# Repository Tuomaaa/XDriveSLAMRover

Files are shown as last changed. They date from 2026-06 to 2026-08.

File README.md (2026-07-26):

# SummerSLAM

SummerSLAM is a 12-week, hardware-backed study of mobile-robot localization
and SLAM on a four-wheel X-drive rover. The public engineering notes share the
design process, failures, measurements, and reproduction path for the first six
weeks, from hardware bring-up through Monte Carlo Localization.

**Reproduction manual / engineering notes:** <https://tuomaaa.github.io/XDriveSLAMRover/>

## Repository map

- `stm32/` - STM32F411 firmware, motor control, encoders, CAN, and ultrasonic sensing
- `ros2_ws/src/` - ROS 2 Jazzy CAN bridge, odometry, measurement models, and localization tools
- `data/` - calibration and validation data
- `docs/textbook/` - Sphinx/MyST source for the Week 1-6 engineering notes
- `PROJECT_STATE.md` - current status, decisions, known issues, and next steps

## Licensing

Original software in this repository is licensed under the [MIT License](LICENSE).
Original engineering-note content and media are licensed under
[CC BY 4.0](LICENSE-DOCS). Third-party components retain their own licenses.

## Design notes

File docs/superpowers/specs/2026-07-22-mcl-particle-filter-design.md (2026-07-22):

# Week 6: MCL Particle Filter — Design Spec

## Goal

Implement Monte Carlo Localization (Prob Robotics Ch.8) for the X-drive rover
in a known rectangular environment, using encoder odometry for prediction and
two HC-SR04 ultrasonic sensors for measurement update.

## Modules

| File | Responsibility | Dependencies |
|---|---|---|
| `mcl.py` | Particle filter core (predict, update, estimate, resample) | `map_model.py`, `measurement_model.py`, numpy |
| `mcl_offline.py` | Offline replay: read CSV, run MCL, produce animation GIF | `mcl.py`, matplotlib |
| `mcl_node.py` | Online ROS2 node (phase 2, after offline validation) | `mcl.py`, rclpy |

All files live in `ros2_ws/src/` alongside existing modules.

## `mcl.py` — Core Algorithm

### Class: `MCL`

```python
MCL(
    rect_map: RectMap,
    beam_model: BeamModel,
    sensor_configs: list[tuple[float, tuple[float, float]]],
    num_particles: int = 500,
    alpha: tuple[float, float, float, float] = (0.05, 0.01, 0.01, 0.05),
    rng_seed: int | None = None,
)
```

**State:**
- `particles`: numpy array shape (N, 3) — each row is (x, y, theta)
- `weights`: numpy array shape (N,) — normalized to sum to 1

**Methods:**

`initialize(x, y, theta, xy_spread, theta_spread)` — scatter particles as
Gaussian cloud around a known starting pose. All particles get weight 1/N.

`predict(dx_body, dy_body, dtheta)` — for each particle:
1. Add proportional Gaussian noise to the body-frame delta:
   - `d_trans = sqrt(dx^2 + dy^2)`
   - `dx' = dx + N(0, alpha[0]*d_trans + alpha[1]*|dtheta|)`
   - `dy' = dy + N(0, alpha[0]*d_trans + alpha[1]*|dtheta|)`
   - `dtheta' = dtheta + N(0, alpha[2]*d_trans + alpha[3]*|dtheta|)`
2. Rotate (dx', dy') from body frame to world frame using particle's theta
3. Update particle pose: x += dx_world, y += dy_world, theta += dtheta'
4. Clamp particle inside map bounds (optional, prevents particles escaping walls)

`update(measurements: list[float | None])` — for each particle:
1. Compute expected range via `rect_map.expected_range(particle_pose, ...)`
2. Compute log-likelihood via `beam_model.total_log_likelihood(...)`
3. Convert to weight, normalize across all particles
4. Low-variance resample

`estimate() -> (x, y, theta)` — weighted mean of particles. Theta uses
circular mean: `atan2(sum(w*sin(theta)), sum(w*cos(theta)))`.

### Low-Variance Resampling

Standard Prob Robotics algorithm: draw one random offset r in [0, 1/N),
then walk through cumulative weight distribution stepping by 1/N. O(N),
deterministic given r, less variance than multinomial resampling.

### Smoke Test

`if __name__ == "__main__"`: create a RectMap, place a "robot" at a known
pose, generate synthetic odometry deltas + noisy range readings, run
predict/update for ~50 steps, assert estimate converges to within 5cm / 5deg
of the true pose.

## `mcl_offline.py` — Offline Replay

### Data Collection

A new script or mode in `can_bridge_node.py` logs to CSV while the robot
drives in the KT board enclosure:

```csv
timestamp_s,odom_x,odom_y,odom_theta,right_mm,back_mm,right_valid,back_valid
```

Each row is emitted whenever a complete encoder+ultrasonic update arrives.
The odometry pose comes from `OdometryEstimator`; ultrasonic fields come
from the 0x202 CAN frame.

### Replay Loop

```
for each row in CSV:
    dx, dy, dtheta = body_frame_delta(prev_odom, current_odom)
    mcl.predict(dx, dy, dtheta)
    if right_valid or back_valid:
        mcl.update([right_m if right_valid else None,
                    back_m if back_valid else None])
    record frame for animation
```

Body-frame delta: rotate world-frame displacement (odom_x - prev_x,
odom_y - prev_y) by -prev_theta to get body-frame (dx, dy).

### Animation Output

Matplotlib FuncAnimation saved as GIF:
- Gray rectangle = map boundary
- Blue dots = particles (alpha proportional to weight)
- Red arrow = MCL estimated pose
- Green arrow = raw odometry pose
- Two sensor rays from estimated pose to measured range
- Frame rate: ~10 fps, one frame per MCL step

## Parameters

| Parameter | Value | Source |
|---|---|---|
| num_particles | 500 | sufficient for 1.165m x 1.165m map |
| alpha | (0.05, 0.01, 0.01, 0.05) | Prob Robotics typical, tune with data |
| sigma_hit | (0.0017, 0.0078) | Week 5 calibration |
| w_hit/short/max/rand | 0.94/0.01/0.03/0.02 | Week 5 calibration |
| z_max | 4.0 | HC-SR04 spec |
| lambda_short | 0.5 | low weight, not critical |
| sensor_configs | [(-pi/2, (0,-.09)), (pi, (-.09,0))] | physical measurement |
| map | RectMap(0, 1.165, 0, 1.165) | KT board measured |

## Initialization

Known initial pose (car placed at measured position). Particles scattered
with xy_spread=0.05m, theta_spread=0.1rad. Global localization (uniform
over entire map) is a stretch goal.

## Testing Strategy

1. **Synthetic smoke test** (`mcl.py __main__`): deterministic RNG seed,
   simulated robot in known map, verify convergence
2. **Offline replay** (`mcl_offline.py`): real sensor data, visual inspection
   of particle convergence and MCL vs odometry divergence
3. **Sanity checks**: particles stay inside map, weights sum to 1, estimate
   moves in correct direction

## Phase 2: Online (`mcl_node.py`) — After Offline Validation

Subscribe to `odom` and `/ultrasonic/right` + `/ultrasonic/back` topics.
On each odom update: compute body-frame delta, call `predict()`.
On each ultrasonic update: call `update()`.
Publish estimated pose on `/mcl_pose` and particles on `/mcl_particles`.
Defer to after offline replay works end-to-end.

## Not In Scope

- Global localization (uniform initialization)
- KLD-sampling / adaptive particle count
- Multi-hypothesis tracking (kidnapped robot)
- Non-rectangular maps
- IMU fusion

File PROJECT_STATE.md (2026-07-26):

# SummerSLAM — Project State

> 最后更新：2026-07-26
> 当前阶段：Week 5 完成 → Week 6。HC-SR04 双超声波全链路跑通（STM32 TIM9 input-capture → CAN 0x202 → RPi sensor_msgs/Range），bench calibration 拟合噪声模型 sigma(d)=0.0017+0.0078d，BeamModel (Prob Robotics Ch.6) + RectMap ray casting 端到端验证通过（4 位置 × 2 传感器，expected vs observed 误差 <1.3mm，log-likelihood true>wrong 全 PASS）。**下一步：Week 6 MCL 粒子滤波定位**

---

## 当前状态

### RPi 系统
- [x] Ubuntu Server 24.04 LTS 已装好
- [x] SSH / 基础配置
- [x] SPI enable
- [x] CAN HAT overlay (Waveshare RS485 CAN HAT, MCP2515, SPI0 CE0, INT GPIO25, 12MHz)
- [x] SocketCAN 验通 (loopback mode, 500kbps)
- [x] ROS2 Jazzy 安装

### PS2 手柄遥控（进行中）
- [x] PS2 协议原理分析（SPI-like, LSB-first, ~25kHz clock）
- [x] RPi 侧 GPIO bit-bang 驱动编写 (ps2_controller.py, /dev/mem + mmap, 零依赖)
- [ ] 驱动实测验证（接收器接线 + analog mode 读取）
- [ ] 摇杆数据 → cmd_vel topic 映射
- 接线：GPIO17→CLK, GPIO27→CMD, GPIO22→DAT, GPIO23→CS, 3.3V供电

### STM32 侧 — CubeMX 配置完成 ✅ / Build 通过 ✅ / 硬件替换完成 ✅
MCU: STM32F411CEU6 (Black Pill)，HSE 25MHz → PLL (M=25, N=200, P=2) → SYSCLK 100MHz。

外设分配：
- **PWM (电机速度)**：TIM1，4 channel (PA8/PA9/PA10/PA11)，Period=4999 → 20kHz
- **Encoder (4 路)**：全部 TIM_ENCODERMODE_TI12，Period 用默认最大值
  - TIM2 (PA15/PB3) — 32-bit, Period=4294967295
  - TIM3 (PB4/PA7) — 16-bit, Period=65535
  - TIM4 (PB6/PB7) — 16-bit, Period=65535
  - TIM5 (PA0/PA1) — 32-bit, Period=4294967295
- **SPI1 (→ MCP2515)**：Master, Mode 0 (CPOL=Low, CPHA=1Edge), 6.25 MBits/s
  - SCK=PA5, MISO=PA6, MOSI=PB5, CS=PB9 (软件控制 GPIO)
- **MCP2515 INT**：PB8, EXTI line 8, falling edge + pull-up, EXTI9_5 IRQ 已 enable
- **USART2 (调试)**：PA2/PA3, 115200 8N1, parity NONE
- **电机方向 GPIO**：PB0/PB1/PB2/PB10/PB12/PB13/PB14/PB15 (8× output push-pull)
- **SWD**：PA13/PA14

Toolchain: CMake (配合 ST 官方 STM32CubeIDE for VS Code extension)。
Build 验证：25 个文件编译+链接通过，RAM 2104B/128KB (1.61%), FLASH 13400B/512KB (2.56%)。

### TB6612 接线（已验证）

TB6612 #1:
- **B 通道 (电机 1)**：PWMB ← PA8 (TIM1_CH1), BIN1 ← PB1 (Motor1_2), BIN2 ← PB0 (Motor1_1)
- **A 通道 (电机 2)**：PWMA ← PA9 (TIM1_CH2), AIN1 ← PB10 (Motor2_2), AIN2 ← PB2 (Motor2_1)
- **电源**：STBY ← 3.3V (常高), VCC ← 3.3V, VM ← 12V (LiPo 直供), GND ← 共地

注意：label 和 TB6612 pin 命名有错位（Motor1_1=BIN2, Motor1_2=BIN1），功能不影响但代码里注意对应关系。

### 硬件事故记录 ⚠️（两次，root cause 未确认）

两次 bring-up 期间均发生 destructive short，但目前没有足够证据确认各自的具体短路点和传播路径。旧记录中的“示波器探针桥接 VM/VCC”只能算假设，不能继续写成已确认原因。

**事故 1 损失**：
- ST-Link V2 clone × 1
- STM32 board × 1
- TB6612 module × 2

**事故 2 损失**：
- STM32 board × 1
- TB6612 module × 1

**总损失**：STM32 × 2、TB6612 × 3、ST-Link × 1。Raspberry Pi 因单独处理 power path 保持安全。

**断电后的 quick triage**：
1. 断开 battery、USB、ST-Link 和所有其他电源
2. 用 multimeter 检查 GND 与 3.3V/5V/12V rail 之间的 resistance/continuity
3. 对可疑芯片检查 GPIO 与 GND，但尽量和同型号 good board 对比
4. 区分 persistent short 与 capacitor charging；蜂鸣不等于板子一定损坏
5. ST-Link 单独插 USB 不亮是本次观测到的 failure symptom
6. 之后用 current-limited bench supply 逐模块重新上电

**教训**：
1. continuity test 只能 triage，不能证明 board 完全正常
2. 12V 与 3.3V/5V wiring 必须物理分开，并在断电后改线
3. 加 fuse/current limit/keyed connector，逐 power branch、逐 motor channel bring-up
4. 备 STM32、TB6612、ST-Link 等低成本 spare，避免单次事故中断整个进度
5. isolated DC-DC 可降低 fault propagation，但若 signal/ground 仍相连就不是完整 galvanic isolation，也不能预防所有 short

### CAN 协议（已定 ✅）

ID 编码：高 3 bits 类别（兼 arbitration 优先级），低 8 bits 子分类。

```
优先级  类别         高3bits   ID范围        方向           频率
──────────────────────────────────────────────────────────────────
0(最高) Error        0b000    0x000~0x0FF   STM32→RPi     event-triggered
1       速度指令      0b001    0x100         RPi→STM32     50~100ms
2       Encoder反馈   0b010    0x200, 0x201  STM32→RPi     20ms (50Hz)
3       Heartbeat    0b011    0x300         RPi→STM32     100ms
4       PID调参       0b100    0x400~0x402   RPi→STM32     event-triggered
5(最低) ACK/Response  0b101    0x5XX         STM32→RPi     event-triggered
```

Payload 格式：
- 0x100 速度指令：4×int16_t 目标RPM (±300RPM, little-endian), 8 bytes
- 0x200 Encoder Frame 0：Motor 0 + Motor 1 各 int32_t 累计ticks, 8 bytes
- 0x201 Encoder Frame 1：Motor 2 + Motor 3 各 int32_t 累计ticks, 8 bytes
- 0x300 Heartbeat：DLC=0 或可选 sequence counter
- 0x400/401/402 PID Kp/Ki/Kd：byte0=motor_index(0~3), byte1+=参数值
- 0x5XX ACK：byte0=原始命令sub-ID, byte1+=可选回传数据

安全机制：
- Heartbeat 100ms 周期，timeout 200ms，超时后 STM32 所有电机 PWM=0
- Error 每种独立 ID，具体 error code 待实现阶段定义
- ACK 提供应用层确认（CAN link-layer ACK ≠ application-layer ACK）

### STM32 固件（进行中）
- [x] CubeMX generate code 后的工程骨架在 VS Code 里 build 通过
- [x] 电机基础驱动验证 (PWM + 方向 GPIO → TB6612 → 电机转)
- [x] Encoder 读取 (TIM2 encoder start + CNT → CAN 0x200 验证通过)
- [x] PWM 输出 + 电机方向 GPIO 控制
- [x] 电机控制：**当前用 open-loop**（`main.c` 的 `#define USE_PID 0`）——摇杆 target RPM 直接映射 PWM duty。**待重新烧录验证**
  - **决策 (2026-07-04)**：遥控 + odometry 阶段不需要闭环，PID 对 odometry 无帮助（odometry 直接读 encoder），且闭环会抹平 Week4 要测的 motion uncertainty。open-loop 还天然免疫下面那个 runaway。
- [x] PID 速度环 (20ms 周期, Kp=8/Ki=2/Kd=0.1)：**代码保留在 `USE_PID` 分支里，当前关闭**，以后 cmd_vel 自主驾驶时翻成 1 恢复
  - **runaway 根因 + 符号修正 (2026-07-04)**：四路 encoder 全反，PID 若用 raw 反向计数当反馈 → 正反馈 runaway（上电即全速、摇杆无效）。已加 `ENC_SIGN[4]={-1,-1,-1,-1}`（仅作用于 PID 反馈，CAN raw ticks 不变，RPi `ENCODER_SIGN=-1` 不用动），随 PID 一起留在 `#if USE_PID` 内。恢复闭环前务必确认 `USE_PID=1` 下不再 runaway
- [x] MCP2515 SPI 驱动 + CAN loopback 收发验证 (thumptech/STM32-MCP2515 库，已修 bug)
- [x] STM32 → RPi 真实 CAN 通信验证 (500kbps, MCP2515 模块需 5V 供电)
- [x] Heartbeat timeout 安全停机 (200ms 内无 0x300 心跳则电机 PWM 清零)
  - **急停失效 bug 修复 (2026-07-04)**：原来 `motors_stop()` 清零后紧随的控制块每 20ms 又把 PWM 顶回去，急停形同虚设。改成用 `hb_ok` 门控整个控制更新（open-loop 与 PID 两种模式都生效），超时时电机保持 0；PID 模式下还清 integral 防 windup。**待重新烧录验证**
- [x] TIM3/TIM4 16-bit encoder overflow 处理 (软件扩展到 int32，与 CAN 协议累计 tick 对齐)
- [x] HC-SR04 双超声波驱动 (hc_sr04.c/h, TIM9 CH1/CH2 input capture, 顺序测距)
  - PA4=TRIG (共享), PA2=Right ECHO (TIM9_CH1), PA3=Back ECHO (TIM9_CH2)
  - **注意**：PA2/PA3 原为 USART2 debug，已让给 TIM9，debug 串口不再可用
  - CAN 0x202 发送 right_mm + back_mm + status (5 bytes)，集成在 20ms 控制循环

### ROS2 CAN Node（进行中）
- [x] CAN 协议 encode/decode 层 (protocol.py)
- [x] SocketCAN interface 封装 (can_interface.py, python-can)
- [x] can_bridge_node.py 设计完成（代码在 chat 中，未部署到 RPi）
- [ ] Heartbeat publisher (100ms)
- [ ] 速度指令 subscriber (topic → CAN 0x100)
  - cmd_vel → 4路RPM 换算暂留 placeholder
- [ ] Encoder 反馈 listener (CAN 0x200/0x201 → topic)
  - Odometry 计算：kinematics 已定，odometry.py 已写好，待接入 node 并发布 nav_msgs/Odometry + TF
- [ ] Error listener (0x0XX)
- [ ] ACK listener (0x5XX)
- [ ] PID 调参 service (0x400~0x402)

### Week3 Kinematics & Odometry（进行中）

- [x] Inverse kinematics 方程确认，对齐 `ps2_drive_test.py` 的实现：
  `fl = vx+vy+ωR`, `fr = vx-vy-ωR`, `rl = vx-vy+ωR`, `rr = vx+vy-ωR`
- [x] Forward kinematics 消元推导完成：
  `vx = (fl+fr+rl+rr)/4`，`vy = (fl-fr+rr-rl)/4`，`ω = (fl-fr-rr+rl)/(4R)`
- [x] Pose integration 用 midpoint method 实现（`θ_mid = θ + ωdt/2`），而非 plain Euler
- [x] `odometry.py` 模块编写完成，独立于 CAN/ROS，`MOTOR_MAP`/`ENCODER_SIGN`/`ENCODER_CPR` 显式暴露为配置，smoke test（纯 vy 输入 → vx=0, ω=0）通过
- [x] Motor index ↔ 物理轮位映射确认并落地：`main.c` 新增 `MotorPosition` enum (`MOTOR_FL=0, MOTOR_FR=1, MOTOR_RL=2, MOTOR_RR=3`)，`motors[]` 初始化、CAN 收发全部改用 enum 索引，跟 `odometry.py` 的 `MOTOR_MAP` 对齐
- [x] `encoder_monitor.py` 编写完成：实时打印四路 encoder tick（从 baseline 起的 delta），配合 `ps2_drive_test.py` 在第二个终端跑，供 Encoder 方向标定用
- [x] Encoder 方向标定（2026-07-04 实机）：直线前进时四路 encoder tick 全部递减，`ENCODER_SIGN` 四路全设 -1。**注意**：纯 vx 前进测试已完全确定四路符号，vy/omega 方向正确性只能靠 Ground truth test 验证，无法再靠 `ENCODER_SIGN` 修
- [x] `ENCODER_CPR` 实机标定（2026-07-04）：四轮各手转 10 圈，FL 2779.5 / FR 2778.3 / RL 2778.7 / RR 2777.6，平均 2778.5，取整 **2779**（理论值 2800 偏高 ~0.8%，轮间极差仅 0.07%）。已更新 `odometry.py`；`main.c` 的 `#define ENCODER_CPR` 暂留 2800（只影响 PID RPM 反馈精度 ~0.8%，是否为此重烧待定）
- [x] **发现并修复 RL/RR encoder 接反（2026-07-06）**：实机方向验证时 vy 和 omega 通道互换（原地转读成 y、横移读成 omega），vx 正常。用 `encoder_monitor.py` 逐个手转物理轮确认是 RL/RR 两路 encoder 物理接反（index 2 在 RR 轮、index 3 在 RL 轮）。修法：`odometry.py` 的 `MOTOR_MAP` 把 index 2↔3 标签对调（`{0:fl,1:fr,2:rr,3:rl}`），只改 odometry 不用重烧。smoke test 顺手重写成按 `ENCODER_SIGN`/`MOTOR_MAP` 反推构造输入（不再硬编码 per-index tick），改配置不会再悄悄失效
- [ ] Ground truth sanity check：正方形轨迹 + 原地转 360°，卷尺量实际终点位置对比代码输出（**待实机**，用 `can_bridge_node.py` 的 pose 日志观察）。先做方向复验：原地转只 theta 变、横移只 y 变、前进只 x 变
- [x] `can_bridge_node.py` 接入 `OdometryEstimator`（2026-07-04）：收齐 0x200+0x201 后调 `update()`（dt 用 CAN 帧时间戳），发布 `nav_msgs/Odometry` on `odom` + `odom→base_link` TF；另加 ~2Hz 节流 pose 日志供 ground-truth 观察。import 改成平铺式（跟全项目一致），`python3 can_bridge_node.py` 直接跑。**代码完成，待实机验证**

### Week5 Ultrasonic Perception（完成 ✅ 2026-07-20）

- [x] HC-SR04 STM32 驱动 (hc_sr04.c/h): TIM9 input-capture, right+back 顺序测距, 共享 TRIG
- [x] CAN 0x202 协议 (protocol.py): encode/decode right_mm + back_mm + status
- [x] can_bridge_node.py 接收 0x202, 发布 `/ultrasonic/right` + `/ultrasonic/back` (sensor_msgs/Range)
- [x] Bench calibration（2026-07-20）: 2 sensors × 4 distances (100/300/600/1000mm) × 100 samples on KT board
  - 噪声模型拟合: `sigma(d) = 0.0017 + 0.0078 * d` (meters)
  - Bias: ~2.4mm + 0.47% of distance (small positive, not corrected)
  - Invalid rate: ~2.9% overall
  - 数据: `data/ultrasonic/bench_calibration.csv`, `data/ultrasonic/bench_summary.csv`
- [x] BeamModel (Prob Robotics Ch.6 四分量 beam model): w_hit=0.94, w_short=0.01, w_max=0.03, w_rand=0.02
- [x] GaussianModel (简化版, 两分量)
- [x] RectMap + 2D ray casting (map_model.py), 支持 sensor offset
- [x] 端到端 map validation（2026-07-20）: 116.5cm KT board 正方形, 4 位置 × 2 传感器
  - Expected vs observed: 全部 8 路误差 <1.3mm
  - Log-likelihood: true pose 得分 > wrong pose (±50mm shift), 全 4 位置 PASS
  - 数据: `data/ultrasonic/map_validation.csv`
- [x] Sensor offset 实测: RIGHT=(-π/2, (0.0, -0.09)m), BACK=(π, (-0.09, 0.0)m)

### Week 1-6 Engineering Notes（Weeks 1-3 first drafts，2026-07-26）

- [x] Sphinx + `sphinx_rtd_theme` + MyST Markdown 文档骨架放在 `docs/textbook/`
- [x] Home、combined Weeks 1-2、Week 3-6、Reproduction/CAN/Calibration/Debugging appendices 接入 `toctree`；旧 Week 2 URL 保留为 orphan compatibility page
- [x] 每章分开标注 chapter status 与 engineering verification state，未完成内容不冒充已验证
- [x] 硬件事故、CAN/firmware 坑、encoder swap、PID runaway、heartbeat 急停覆盖、frame/scale 修正全部建立 cross-reference
- [x] GitHub Actions workflow：PR 只做 strict build，`main` 文档改动 build + deploy 到 GitHub Pages
- [x] 原创 code 使用 MIT，原创 engineering-note content/media 使用 CC BY 4.0，署名 Thomas Pan；第三方 license 保持不变
- [x] Local strict Sphinx build + desktop/mobile visual QA：pinned Sphinx 9.1.0 toolchain 下 `-W --keep-going` 零 warning；1440×900 / 390×844 检查 sidebar、mobile nav、search、公式、架构图、footer license、Prev/Next 均通过，无 horizontal overflow / broken image
- [ ] External linkcheck：当前 remote `main` 尚无本地 ahead 的 Week 5/6 commits，因此对应 GitHub links 在 push 前返回 404；push 后重新执行 linkcheck
- [ ] GitHub repo Settings → Pages → Source 切到 GitHub Actions，并在 push 后验证公开 URL：`https://tuomaaa.github.io/XDriveSLAMRover/`
- [x] Weeks 1-2 combined chapter：完整保留 mechanical/electrical selection、CubeMX/CMake/CubeProgrammer workflow、motor/encoder/CAN/PS2 bring-up 和两次 power incidents；页面不再使用 TODO/placeholder box，未知事故根因仍明确标作 unproven
- [x] Weeks 1-2 media pass：接入 22 张页面图片（rover、layers、parts、SolidWorks、wiring preview）、drive-test MP4 和 full wiring PDF；Fritzing/KiCad source 保留 repo link
- [x] Weeks 1-2 PCB lesson 修订：先用 Dupont 验证并 finalize wiring；不要因 right-angle routing、SI/PI、crosstalk 等高级建议而拖延第一版 PCB；wiring 不再变化后直接画板，并在 kinematics 阶段并行等待制造
- [x] Weeks 1-2 repository reading guide：加入 48 个 repo links，按 `.ioc` → CMake → `main.c` → MCP2515/protocol → monitor/controller tools 给出阅读顺序，并对关键 function 使用 line link 说明读者应观察的 control flow
- [x] Weeks 1-2 clear-English pass：保留 PWM、encoder、CAN、galvanic isolation、SI/PI、ERC、DRC 等必要术语和完整 reasoning；平均约 14.0 words/sentence，heuristic Flesch-Kincaid Grade 约 7.5
- [x] Weeks 1-2 clean strict rebuild：Sphinx 9.1.0 + MyST 5.1.0、`-E -W --keep-going` 零 warning；local HTTP page、22 image assets、drive-test video 和 wiring PDF 均返回 200；两个 debugging anchors 与全部关键 source line targets 已复核
- [x] Week 3 process chapter：完整覆盖 frame convention、cumulative ticks、CPR、map/sign/frame/scale 分离、inverse/forward kinematics、REP-103 与 $\sqrt{2}$ correction、CAN timestamp、midpoint integration、CAN/ROS boundary 和全部 debugging trail；正文不再使用 TODO/evidence/diagram placeholder
- [x] Week 3 unit explanation 修订：区分物理 wheel-velocity 模型中的 `omega*R` 与 `PS2_Drive_Test.py` 的 normalized joystick `omega`；明确当前 manual controller 不是 SI-unit `cmd_vel` → wheel-RPM conversion，避免读者混用两层单位
- [x] Week 3 repository reading guide：加入 35 个 repo/data links，按 STM32 motor order → CAN decoder → encoder monitor → odometry config/update → ROS publication → controller convention 给出阅读顺序；关键 constant/function 使用有效 line link
- [x] Week 3 code walkthrough pass：新增 8 组短 snippet（geometry/calibration constants、tick conversion、two-frame CAN pairing、normalized inverse kinematics、forward kinematics、midpoint integration、ROS estimator handoff、heartbeat safety gate），页面共 13 个 code blocks；每段都紧跟公式/故障解释并与对应 repo implementation 对照
- [x] Week 3 clear-English pass：保留全部 technical terms、公式、实测数字与局限说明；平均约 14.9 words/sentence，heuristic Flesch-Kincaid Grade 约 9.6（technical vocabulary 计入）
- [x] Week 3 clean strict rebuild + code smoke test：Sphinx `-E -W --keep-going` 零 warning；local HTTP Week 3 返回 200；36 个 local repo targets 与 3 个 debugging anchors 均复核；`python ros2_ws/src/odometry.py` 验证 physical-left input 得到 `vy>0` 且 `vx=omega=0`
- [ ] Weeks 1-3 desktop/mobile visual re-QA：本次 browser runtime 因 Windows `CreateProcessWithLogonW 1385` 无法启动；此前 scaffold 的 layout QA 通过，但合并后的长正文和 Week 3 公式页尚未重新截图检查
- [ ] 收集可公开的 BOM/clean CAD drawing/power/toolchain/PCB evidence 后继续补 Weeks 1-2；Week 3 后续补 frame/kinematics diagrams、CPR raw data、encoder-map evidence、Euler-vs-midpoint plot 和 ROS odometry capture；之后扩写 Week 4
- **注意**：Week 6 MCL design/plan 在 `main`，实现仍在 `week6-mcl` branch；合并并重新验证前 notes 必须保持 `In progress`

---

## 决策记录

| 日期 | 决策 | 理由 |
|---|---|---|
| 2026-06-04 | Ubuntu Server 24.04 而非 RPi OS | ROS2 Jazzy 官方支持，apt 直装 |
| 2026-06-04 | Loopback mode 先行开发 | 无 STM32，MCP2515 自发自收测试 |
| 2026-06-04 | Kinematics 后做 | 先搭 CAN+ROS2 管道，底盘构型独立 |
| 2026-06-04 | 速度指令发目标 RPM 而非 PWM duty | 保证 STM32 侧是闭环 PID 速度控制 |
| 2026-06-04 | Encoder 发累计 ticks 而非 delta | 累计值 idempotent，丢帧不累积误差 |
| 2026-06-04 | Encoder 按电机拆帧而非按字节高低拆 | 每帧 self-contained，parsing 简单 |
| 2026-06-04 | PID Kp/Ki/Kd 每参数一帧 | 调参是低频事件，代码简洁性 > 帧效率 |
| 2026-06-04 | ACK 单独开 0x5XX 类别 | 与调参命令方向相反，混用同 ID 范围会导致 filter 混乱 |
| 2026-06-04 | Heartbeat timeout 200ms (2× 周期) | CAN 可靠性高，2× 已足够；bus traffic 轻 |
| 2026-06-07 | Toolchain 选 CMake | 配合 ST 官方 VS Code extension（基于 CMake 构建系统）|
| 2026-06-07 | 4 路 encoder 统一 TIM_ENCODERMODE_TI12 | 两路边沿都计数，4× 分辨率；四电机一致才能正确算 odometry |
| 2026-06-07 | TIM3 EncoderMode 手动编辑 .ioc 修复 | CubeMX bug：pin 配了 Encoder_Interface 但 timer 参数没写入，GUI 反复操作无效 |
| 2026-06-08 | 电机驱动测试优先于 CAN 通信 | 先验证最底层硬件（PWM+TB6612+电机），再搭通信管道；出问题好定位 |
| 2026-06-12 | protocol.py 为 stateless encode/decode 层 | 不持有状态、不做 buffer，纯翻译器；状态管理交给 can_bridge_node |
| 2026-06-12 | Category 常量（ERROR/ACK/MASK）不放入 MsgId IntEnum | 它们是 bitmask 不是 message ID，混入 IntEnum 会导致 MsgId(0x000) 等误匹配 |
| 2026-06-12 | decode() 用 if/elif 而非 match/case | Python match 对非 dotted 名称会当 capture pattern，bare constant 不做比较 |
| 2026-06-12 | can_interface.py 薄封装 python-can | 只管 bus 生命周期和收发 raw frame，不碰协议逻辑或 ROS2；channel 参数支持 vcan0 测试 |
| 2026-06-13 | MCP2515 驱动用 thumptech/STM32-MCP2515 库 | STM32F4 HAL 兼容，API 干净，只需改 SPI handle + CS pin + 补 can.h |
| 2026-06-13 | MCP2515 模块晶振 8MHz | 模块实测标 "8.000"，初始化用 MCP_setBitrateClock(CAN_500KBPS, MCP_8MHZ) |
| 2026-06-13 | MCP2515+TJA1050 模块供 5V | TJA1050 需 5V 才能输出正确 CAN 电平 (~2.5V idle)；模块有板载 LDO 给 MCP2515 降压 3.3V，SPI 逻辑电平不受影响 |
| 2026-06-14 | PS2 手柄接 RPi 而非 STM32 | STM32 GPIO 已全部用完（PWM×4 + Encoder×8 + SPI+CS+INT + UART + Direction×8 + SWD），RPi 有空闲 GPIO |
| 2026-06-14 | PS2 驱动用 /dev/mem + mmap 而非 RPi.GPIO | RPi 网络不通无法 apt install，mmap 直接操作 BCM2711 寄存器，零外部依赖 |
| 2026-06-14 | PS2 接收器供 3.3V | RPi GPIO 不是 5V tolerant（不像 STM32 F411），PS2 手柄 spec 支持 3V~5V |
| 2026-06-14 | RPi 供电走 GPIO Pin 2 (5V) 而非 USB-C | UBEC 5V 直供，避免杜邦线→USB-C 的压降和接触问题；注意绕过了 polyfuse |
| 2026-07-03 | Motor index 0/1/2/3 直接对应 fl/fr/rl/rr | 跟 `ps2_drive_test.py` 里已验证过的 inverse kinematics 顺序保持一致，不引入第二套编号 |
| 2026-07-03 | dt 用 CAN 帧实际到达时间戳算，而非固定 20ms | 避免 CAN bus jitter / RPi 调度延迟被当成系统性速度偏差，混进 Week4 要测的 motion uncertainty 里 |
| 2026-07-03 | Pose integration 用 midpoint method (`θ_mid = θ + ωdt/2`) | Plain Euler 在原地快速转弯时位移方向系统性偏差；heading error 比 translational error 更致命 |
| 2026-07-03 | `ENCODER_CPR` 暂用理论值 2800，标定列为 TODO 而非阻塞项 | 先把 kinematics 代码跑通，标定可并行/稍后做，但显式记录，防止被误当成已标定值直接用于 Week4 |
| 2026-07-03 | 确认 motor index 物理映射：TIM2(idx0)=FL, TIM3(idx1)=FR, TIM4(idx2)=RL, TIM5(idx3)=RR | review `main.c` 时发现物理映射从未显式写出，只存在于接线事实里；补了 `MotorPosition` enum + 注释，把 main.c、`odometry.py` 的 `MOTOR_MAP`、`ps2_drive_test.py` 的顺序统一成同一份 single source of truth |
| 2026-07-04 | `ENCODER_SIGN` 四路全设 -1 | 实机直线前进时四路 encoder tick 全部递减；纯 vx 前进测试对每路符号是完全约束（每轮必须前进=正），四路一致翻负即可。副作用：vy/omega 也随之翻号，其方向正确性无法再靠 sign 修，只能靠 ground-truth test 验证 |
| 2026-07-04 | `ENCODER_CPR` 用实测 2779 替换理论 2800 | 四轮各手转 10 圈实测：FL 2779.5/FR 2778.3/RL 2778.7/RR 2777.6，均值 2778.5 取整。轮间极差仅 0.07%，用单一全局值足够；理论值偏高 0.8% 属 N20 减速箱正常 |
| 2026-07-04 | `main.c` 的 `ENCODER_CPR` 暂不同步改（留 2800） | STM32 侧该宏只用于 PID 的 RPM 反馈换算，0.8% 误差对速度环无实际影响；改它要再烧一次录，收益不值，待有其他固件改动时顺带更新 |
| 2026-07-04 | odometry 触发时机：收到 0x201（完成 0/1/2/3 全套）时调 update() | STM32 每 20ms 先发 0x200 再发 0x201，以 0x201 为"一组完整"信号最简单；用该帧 `msg.timestamp` 算 dt。若丢 0x200 会把上一帧的 FL/FR 和新 RL/RR 配对，但累计 tick idempotent，单帧误配影响极小，可接受 |
| 2026-07-04 | `can_bridge_node.py` 用平铺 import + `python3` 直跑，不建 colcon 包 | 全项目其它脚本都是平铺 import + 裸跑，无 `package.xml`/`setup.py`；为一个 node 单独搭 package 结构收益低。ground-truth 阶段靠 node 自带 2Hz pose 日志观察，不需要 `ros2 launch` |
| 2026-07-04 | 电机控制先用 open-loop（`USE_PID=0`），PID 保留待 cmd_vel 阶段 | 遥控 + odometry 标定/drift 阶段不需要速度闭环；PID 对 odometry 无帮助（直接读 encoder），且闭环会补偿掉 Week4 要测量的 motion uncertainty。open-loop 也天然免疫 encoder 反向导致的 PID 正反馈 runaway。PID 代码用 `#if USE_PID` 完整保留，翻成 1 即恢复 |
| 2026-07-04 | 急停门控从"清零后被覆盖"改为 `hb_ok` 门控整个控制更新 | 原逻辑 `motors_stop()` 之后控制块又立即重驱 PWM，导致 heartbeat 急停失效（断心跳也停不下来）。现在心跳超时时整个控制更新短路，电机保持 0；encoder_update 仍每 20ms 跑以维持 CAN ticks 与 16-bit overflow 追踪 |
| 2026-07-06 | `MOTOR_MAP` 后两位（index 2/3）故意与 drive 侧不一致 | 实测 RL/RR 的 encoder 线束物理接反，与 motor 线束是两套独立接线。`MOTOR_MAP` 反映的是 **encoder 接线**（index2=rr, index3=rl），不能为"对齐" `main.c` 的 `MotorPosition` enum 而改回去。判据：vy/omega 互换而 vx 正常 = 轮位映射交换，非 sign/公式问题 |
| 2026-07-06 | forward kinematics 的 `vy`/`omega` 输出翻号，对齐 REP-103 | RL/RR map 修好后方向复验：横移左读成 -vy、CCW 读成 -omega，而 vx（前进）正常。「vx 对、vy+omega 同时反」= 左右镜像，说明 drive 侧逆解约定里 +vy 指向右、+omega 是 CW。`ENCODER_SIGN` 被前进测试钉死、`MOTOR_MAP` 被物理接线钉死，这个 frame 镜像只能在输出端修：`odometry.py` 里 `vy`/`omega` 前加负号，vx 不动（本就 REP-103 正确）。改的是**输出坐标约定**，不是 drive 侧命令约定（遥控手感是另一码事，见"不在本次范围"）|
| 2026-07-06 | `odometry.py` 平移补 `√2`（`TRANSLATION_SCALE`），旋转不动 | Task4 海绵 ground-truth（`data/Week4 Trials.xlsx`）：前进+横移 odom 都读实测的 ~0.74，而原地转读 ~1.0。这个"平移偏低、旋转正常"= X-drive 45° 轮的 `cos45=1/√2=0.707` 投影因子在**未归一化逆解**里缺失（drive 侧 `PS2_Drive_Test.py` 与本文件都用系数=1）；旋转项用 `ωR` 不带投影故不受影响。geometry 保证 + 实测 0.74 双重支持。修法：`vx,vy` 各乘 √2，omega 不动。**drive 侧逆解暂不改**（只影响遥控速度标定，不影响方向；cmd_vel 阶段再统一）。剩余 0.74→0.707 的 ~5% 是海绵打滑/CPR 小残差，待硬地或大海绵长距复测再抠 |
| 2026-07-06 | `PS2_Drive_Test.py` 加 D-pad 微调（`MICRO_RPM=50`） | 遥控摇杆太粗，ground-truth 时对不准地面标记。方向键 上/下=前后、左/右=横移，叠加一个固定小 RPM crawl 在摇杆之上（摇杆归中时即纯慢速微调）。body-frame 约定与摇杆一致（+vx 前、+vy 左）。用 `PS2.is_pressed(btn1, BTN_*)` 读，active-low |
| 2026-07-20 | PA2/PA3 从 USART2 改给 TIM9 (HC-SR04 echo) | STM32 GPIO 全部用完，超声波 echo 需要 input-capture timer，PA2/PA3 是 TIM9 唯一可用 pin。USART2 debug 串口牺牲，改用 CAN 帧观察调试 |
| 2026-07-20 | 两个 HC-SR04 共享一根 TRIG 线 + 软件顺序测距 | GPIO 不够分两根 TRIG。hc_sr04.c 用状态机保证先测 right 再测 back，间隔 60ms 避免 crosstalk。实测 invalid 率 ~3%，没有观察到双峰 |
| 2026-07-20 | 噪声模型用两传感器合并拟合而非分别建模 | 两传感器 std 趋势几乎一致（per-sensor fit 差异 <0.5mm），分别建模增加参数但不增加 MCL 区分度。合并后 sigma(d) = 0.0017 + 0.0078*d |
| 2026-07-20 | BeamModel 权重 w_hit=0.94/w_short=0.01/w_max=0.03/w_rand=0.02 | 实测数据非常干净：无 crosstalk、无 multipath 短读数，invalid 率 ~3% 直接映射到 w_max。w_short 保留极小值兜底 |
| 2026-07-20 | Bias (~2.4mm + 0.47% of distance) 不补偿 | bias 绝对值 <8mm@1m，远小于 MCL 粒子间距（通常几十mm），补偿收益不抵引入的复杂度。如果将来 MCL 精度不够再回来加 |
| 2026-07-26 | Engineering Notes 用 Sphinx + `sphinx_rtd_theme` + MyST，GitHub Pages 作为 repo 首页 | 复用 PythonRobotics 的 Read the Docs layout，但内容定位为 first-person reproduction/process journal；首发只展示 Week 1-6 |
| 2026-07-26 | Code 用 MIT、engineering-note content/media 用 CC BY 4.0（Thomas Pan） | 软件与原创内容复用边界清楚；STM32 HAL、CMSIS 等第三方内容继续服从各自 license，不被 root license 重新授权 |
| 2026-07-26 | Week 1 hardware 与 Week 2 programming 合并成一个 Weeks 1-2 chapter | 实际 bring-up workflow 无法把 hardware verification 和 exercising firmware 分开；旧 Week 2 URL 用 orphan compatibility page 保持稳定，sidebar 不重复展示 |

---

## 已知坑 / Workaround

- **CubeMX TIM3 encoder mode 不写入**：pin SH 配置正确 (Encoder_Interface) 但 `TIM3.EncoderMode` 行不生成，GUI 怎么切都没用。默认值是 TIM_ENCODERMODE_TI1（只单路计数），会导致该轮分辨率只有其他轮的 1/4。Workaround：文本编辑器直接在 .ioc 加 `TIM3.EncoderMode=TIM_ENCODERMODE_TI12` 和 `TIM3.IPParameters=EncoderMode`，再 regenerate。
- **Encoder Period 默认值是最大值不是 0**：CubeMX GUI 默认就填了 16-bit=65535 / 32-bit=4294967295，.ioc 里没显式写出来只是因为没改过默认值，generate code 用的是 GUI 显示值。无需手动改。
- **ST VS Code extension import 可能报 "project corrupted"**：clean project 从 CubeMX 重新 generate code 后直接打开可以绕过。
- **12V 与 low-voltage adjacency 风险**：TB6612 的 VM (12V) 和 VCC (3.3V) 引脚相邻，任何 wiring/probing short 都可能把高压带入 low-voltage rail。两次实际事故的具体 root cause 均未确认；测量或改线前必须断开全部电源。
- **Python match/case capture pattern 陷阱**：`case ENCODER_0:` 里的 bare name 会被当成新变量捕获任意值，不会比较常量。要么用 dotted name `case MsgId.ENCODER_0:`，要么用 if/elif 代替。
- **thumptech/STM32-MCP2515 库 sendMessageTo bug**：`readRegister(rts_addr)` 用 RTS 指令码 (0x81) 当寄存器地址读，读到垃圾值导致 ERROR_FAILTX。修复：改成 `readRegister((txbn + 3) << 4)` 读真正的 TXBnCTRL (0x30/0x40/0x50)。
- **thumptech/STM32-MCP2515 缺 can.h**：仓库没提供 `can_frame` 定义和 Linux SocketCAN 常量（CAN_EFF_FLAG 等），需自建 can.h，typedef struct 而非 struct（C 兼容）。
- **CMake 手动添加源文件**：CubeMX regenerate 会覆盖 CMakeLists.txt，手动加的 mcp2515.c 条目会丢失，需重新添加。
- **RPi WiFi DHCP 不分配 IPv4**：netplan 配置正确，wlan0 状态 UP 但无 IPv4 地址，只有 IPv6 link-local。`netplan apply` 后偶尔恢复。SSH 通过 IPv6 或缓存 session 维持。不影响 CAN / GPIO 开发。
- **RPi 不是 5V tolerant**：RPi GPIO 输入最大 3.3V，不像 STM32 F411 有 FT pin。PS2 接收器、任何外设模块的 DATA 线输出如果是 5V 会烧 RPi GPIO。
- ~~**`ENCODER_CPR=2800` 是理论计算值**~~ **已标定 (2026-07-04)**：`odometry.py` 用实测 2779（四轮均值）。注意 `main.c` 侧仍是 2800（见决策记录，PID 反馈用，暂不改）；两处值不一致是有意为之，别当成 bug 又改回去。
- ~~**`can_bridge_node.py` import 路径已断**~~ **已修 (2026-07-04)**：改成平铺 import（`from protocol import`、`from can_interface import`、`from odometry import`），跟全项目其它脚本一致。整个 `ros2_ws/src/` 没有 `package.xml`/`setup.py`，本来就不是 colcon 包，全部脚本都靠 `python3 xxx.py` 跑（node 需先 `source /opt/ros/jazzy/setup.bash`）。若将来要 `ros2 launch` / 参数管理再补齐 package 结构。
- **Motor index ≠ 物理轮位，需要显式 MOTOR_MAP**：CAN 协议按 motor index (0~3) 传 encoder 数据，但 forward kinematics 公式用的是物理轮位 (fl/fr/rl/rr)。两者对应关系只能靠接线约定，不能从协议或代码反推。`main.c` 里加了 `MotorPosition` enum (FL=0/FR=1/RL=2/RR=3) 描述 **motor/drive 接线**。
- **⚠️ encoder 接线 ≠ motor 接线，`MOTOR_MAP` 后两位与 enum 不一致是对的 (2026-07-06)**：实测 RL/RR 的 encoder 物理接反，所以 `odometry.py` 的 `MOTOR_MAP` 是 `{0:fl,1:fr,2:rr,3:rl}`，index 2/3 跟 `main.c` 的 `MotorPosition` enum（motor 侧）**故意相反**。encoder 与 motor 是两套独立线束，不要为"统一"把它改回去。诊断判据：**vy/omega 互换而 vx 正常 = 轮位映射交换**（不是 sign、不是公式）。

---

## 整车供电方案（当前状态；isolation topology 待补图确认）

**电源**：3S 1500mAh 35C LiPo，记录标称 11.4V (XT60) → XT60 分线

**12V 直供（从 LiPo）**：
- TB6612 × 2 的 VM（电机电源）

**最初 5V 供电（shared UBEC 5V 5A）**：
- RPi、STM32 和 MCP2515+TJA1050 最初共用一个 5V/5A UBEC branch

**当前 5V 供电**：
- RPi 4B（8GB RAM，32GB microSD）← 独立的 5V/5A supply branch；具体 power-entry pin 和 protection 需要在 power-tree 图中复核
- STM32 Black Pill ← motor-control 侧 5V branch
- MCP2515+TJA1050 模块 ← motor-control 侧 5V branch（TJA1050 需要 5V，模块板载 LDO 给 MCP2515 降压 3.3V）
- 这样做降低 motor-control fault 传播到 RPi 的概率，但在 ground 和 communication topology 完整确认前，不能称为已验证的 galvanic isolation

**3.3V**：
- TB6612 × 2 的 VCC（逻辑电源）← 从 STM32 3.3V pin 取或单独稳压
- PS2 接收器 ← RPi 3.3V pin（RPi GPIO 不是 5V tolerant，必须 3.3V）

**注意**：补 power-tree 图时必须明确两个 5V converter、ground、CAN signal path、fuse/current limit 和 RPi power-entry。若要 true galvanic isolation，power 与跨域 signal 都要按隔离方案设计；isolated DC-DC 也不能预防所有 12V short。

---

## Engineering Notebook（本 session 记录）

### Session 目标

推进 Week3→Week4 的 ground-truth / drift 前置工作：把 odometry 的方向、尺度、测试流程和现场操作问题（摇杆太粗、地面 slip、硬件偏航）理顺，做到能在实机上稳定收数据。

### 现场观测 / 现象

1. **方向问题（第一轮）**
   - 原地转被读成 y 变化、横移被读成 omega，前进 x 正常。
   - `encoder_monitor.py` 手转物理轮确认：**RL / RR 两路 encoder 物理接反**。

2. **方向问题（第二轮）**
   - 修完 RL/RR map 后，横移左读成 `-vy`，CCW 读成 `-omega`，但前进 `+x` 正常。
   - 结论：不是 sign，也不是 map，而是**输出坐标约定左右镜像**；drive 侧逆解约定里 `+vy` 实际指向右、`+omega` 指向 CW。

3. **尺度问题（foam ground-truth）**
   - `data/Week4 Trials.xlsx`:
     - 前进 / 横移：odom 约为实测的 **0.74×**
     - 原地转：odom 约为实测的 **~1.0×**（但 actual 是 eye test，只能粗看量级）
   - 结论：这是 **X-drive 45° 轮缺 `cos45 = 1/√2` 投影因子** 的经典指纹。平移少了 `1/√2`，旋转不受影响。

4. **硬件偏航**
   - Test1 前进时 `theta` 稳定落在 `-7° ~ -11°`，肉眼也看到明显转向。
   - 结论：这是 **open-loop + 单电机阻力不均** 的物理偏航，odometry 在忠实记录，不是 odom bug。短期内不修，把它当作 Week4 uncertainty 的一部分。

5. **地面选择**
   - 用户实测：**光滑硬地板误差很离谱，可以 ignore**。
   - 进一步澄清：这里不是“硬地一定更准”，而是**这台 X-drive 在光滑地面对 driven 分量抓地差，translation slip 太大**；反而海绵更咬地。
   - 原本海绵的唯一短板是面积太小（0.6m×0.6m，距离短、量测噪声大）；后来用户确认已有 **约 1m×1m 海绵**，这个短板被补掉。

6. **测试操作问题**
   - 用户指出：PS2 摇杆做不了微调，对准地面标记很困难。
   - 结论：需要给遥控加一个**低速 crawl / nudge 模式**，专门给 ground-truth 对位。

### 本 session 的代码改动

#### 1) `ros2_ws/src/odometry.py`

- **修 RL/RR encoder swap**
  - `MOTOR_MAP` 从 drive 顺序改成 encoder 物理顺序：
    - `0: fl`
    - `1: fr`
    - `2: rr`
    - `3: rl`
  - 注释明确写出：encoder 接线与 motor 接线是两套独立线束，后两位与 `main.c` enum 不一致是**故意的**。

- **修 REP-103 方向**
  - forward kinematics 输出端把 `vy` / `omega` 翻号：
    - 左 = `+y`
    - CCW = `+omega`
  - `vx` 保持不变（本来就对）。

- **补平移 `√2` 尺度**
  - 新增 `TRANSLATION_SCALE = math.sqrt(2)`。
  - `vx`、`vy` 各乘 `TRANSLATION_SCALE`；`omega` 不动。
  - 注释记录依据：foam ground-truth 平移 ~0.74×、旋转 ~1.0×，与缺失 `cos45` 完全一致。

- **smoke test 重写并保持稳健**
  - 不再硬编码 per-index ticks，而是通过 `MOTOR_MAP` + `ENCODER_SIGN` 反推 raw ticks。
  - 这样以后再改 map/sign，test 不会悄悄失效。

#### 2) `ros2_ws/src/PS2_Drive_Test.py`

- **加 heartbeat 线程**（本 session 之前已完成，但本 session 继续沿用验证）
- **加 D-pad 微调模式**
  - `MICRO_RPM = 50`
  - D-pad:
    - 上 / 下 = 前进 / 后退
    - 左 / 右 = 左移 / 右移
  - 逻辑上是给 `vx` / `vy` 叠一个固定小 crawl；摇杆归中时就变成纯微调。
  - 目的：让用户在 ground-truth 时可以把车**慢慢蹭到地面标记上**。

### 本 session 的验证

- `python odometry.py` smoke test 通过：
  - `vx = 0`
  - `omega = 0`
  - `vy > 0`
- `python -m py_compile PS2_Drive_Test.py` 通过。
- 代码已 commit & push：
  - `2b015ab` — `odometry: fix swapped RL/RR encoders in MOTOR_MAP`
  - `16bfac0` — `odometry: flip vy/omega sign to REP-103 (left=+y, CCW=+omega)`
  - `c7492f3` — `odometry: bake in sqrt2 translation scale; PS2: add D-pad fine-adjust`

### 本 session 的测试方法 / 实验设计决策

1. **平移尺度怎么量**
   - 不要求车走直线；允许它因为硬件问题拐弯。
   - 真正拿来比的是：
     - 卷尺量的 **起点→终点净位移直线距离**
     - odom 的 `sqrt(x^2 + y^2)`
   - 因为偏航不破坏这个比值，所以即便路径是弧线，平移 scale 仍然可测。

2. **旋转数据怎么用**
   - 用户补充：所有 omega actual 基本都是 **eye test 的大致 180/360**，本身误差不小。
   - 因此：旋转数据只拿来证明“量级对、旋转不需要 √2”，**不拿来抠 `CENTER_TO_WHEEL_M` 的精度**。

3. **地面怎么选**
   - 放弃光滑硬地。
   - 使用 **1m×1m 海绵** 做长距离复测，既保留低 slip，又把距离拉长到 ~0.6–0.7m，降低量测噪声。

4. **速度怎么选**
   - 不推满，不慢挪。
   - 原则是：**中等稳速、每 trial 尽量一致**。
   - 理由：
     - 太快 → 猛起步/急停导致 slip
     - 太慢 → 落入死区，弱电机可能根本不转

5. **样本量建议**
   - 前进：10 次（既测 scale，也估偏航 std）
   - 横移：5–6 次（验证 y 轴 scale 是否一致）
   - 原地转：5 次（只看量级）
   - 正方形：可选，主要看硬件导致的累积偏航，不作为尺度依据

6. **正方形怎么解释**
   - 在这台车上，正方形“闭不闭合”主要反映硬件偏航，不是 odometry 本身。
   - 真正该比的是：**odom 报的终点姿态 vs 实际终点姿态是否一致**。
   - 所以正方形只是附加实验，不是主尺度实验。

### 当前结论（截至本 session 结束）

- odometry 的三件核心事都已理顺：
  1. **map**（RL/RR encoder swap）
  2. **sign / frame convention**（REP-103）
  3. **translation scale**（√2）
- `can_bridge_node.py` 可继续直接用于 ground-truth 读数。
- 目前最大的非理想项不是 odometry 数学，而是：
  - **open-loop 单电机不均导致的偏航**
  - **实际测试地面的抓地特性**
  - **旋转 actual 量测本身比较粗**

### 下一步（从这个 session 接下去）

1. Pi `git pull`，带上：
   - `odometry.py` 的 RL/RR + REP-103 + √2
   - `PS2_Drive_Test.py` 的 D-pad 微调
2. 在 **1m×1m 海绵** 上做新一轮 Task 4：
   - 前进 ~0.6–0.7m × 10
   - 左移 ~0.6m × 5–6
   - 原地转（粗测量级）× 5
3. 把新数据回填到 `data/Week4 Trials.xlsx` 或新表
4. 用新数据：
   - 验证 √2 修正后平移是否接近 1.0× 实测
   - 量化偏航的 mean / std，作为 Week4 motion uncertainty 输入
5. 若需要，再用 `encoder_monitor.py` 做“弱轮定位”（看纯前进时哪列 tick 增速偏少）

---

## 下一步

1. **Week 6 — MCL 粒子滤波定位**：用 encoder odometry 做 motion update，用超声波 BeamModel 做 measurement update，在 KT 板矩形地图内可视化粒子收敛
2. **Ground truth sanity check**：在 1m×1m 海绵上做长距复测（前进 / 横移 / 粗旋转），更新 Week4 数据表（仍待做）
3. **弱轮定位**：用 `encoder_monitor.py` 看纯前进时哪一路 tick 增速明显偏少，确认偏航根因
4. **RPi 网络修复**：WiFi DHCP 不分配 IPv4 地址，需排查（不影响 CAN 和 GPIO 开发）
5. **Engineering Notes Weeks 1-3 review**：审阅 combined platform/programming narrative 与 Week 3 concept draft；补硬件 evidence 和 Week 3 diagrams/data/ROS capture 后开始 Week 4

---

## 文件结构（规划）

```
summerslam_ws/
├── src/
│   └── can_bridge/          # ROS2 package
│       ├── can_bridge/
│       │   ├── __init__.py
│       │   ├── can_interface.py    # SocketCAN 封装
│       │   ├── can_bridge_node.py  # 主 node
│       │   ├── heartbeat.py        # heartbeat timer
│       │   ├── protocol.py         # CAN ID/payload 定义
│       │   ├── odometry.py         # x-drive forward kinematics + midpoint pose integration
│       │   └── ps2_controller.py   # PS2 手柄 GPIO bit-bang 驱动
│       ├── launch/
│       ├── config/
│       ├── package.xml
│       └── setup.py
```

---

## 参考文档

- `can_protocol_notebook.html` — 协议完整规格（ID/payload/timing/安全机制）
- `can_protocol_process_log.html` — 设计推导过程记录

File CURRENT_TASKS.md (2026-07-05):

# Week 3-4 当前任务

目标：完成 encoder odometry 的硬件验证，然后进入 drift 测量实验。

## 背景

`odometry.py` 已经写好（forward kinematics + midpoint pose integration），smoke test 通过。但所有参数都还是理论值，encoder 方向也没验证过。这次要在实机上把这些参数定下来，确认 odometry 输出跟真实物理运动一致，然后跑重复轨迹收集 drift 数据。

## 任务（按顺序）

### 1. 心跳问题

STM32 固件有 heartbeat timeout（200ms 无 0x300 帧则停机）。当前 `ps2_drive_test.py` 如果没有单独起一个线程/定时器定期发 0x300，电机不会响应任何速度指令。检查 `ps2_drive_test.py` 是否已包含心跳逻辑，如果没有则加上（100ms 周期发送 0x300，DLC=0）。

### 2. Encoder 方向标定

用 `ps2_drive_test.py` 分别执行：
- 纯 vy 运动（只推左摇杆 X 轴）：观察四路 encoder tick 的符号，对照 `odometry.py` 里 inverse kinematics 的预期（fl=+, fr=-, rl=-, rr=+）
- 纯 omega 运动（只推右摇杆 X 轴）：同理检查

如果某路 encoder 符号跟预期相反，更新 `odometry.py` 里对应的 `ENCODER_SIGN` 为 -1。

需要一个脚本或 `ps2_drive_test.py` 的模式来实时打印四路 encoder 的 raw tick 值（从 CAN 0x200/0x201 读取），方便观察。

### 3. ENCODER_CPR 实测标定

手动转某一个轮子的输出轴精确 10 圈，记录 encoder CNT 差值。实测 CPR = delta_ticks / 10。对四个电机都做一遍（可以不完全一样）。用实测平均值替换 `odometry.py` 和 `firmware/Core/Src/main.c` 里的 `ENCODER_CPR` 宏。

### 4. Ground truth sanity check

用 `ps2_drive_test.py` 手动驾驶机器人走：
- 正方形轨迹（边长约 0.5m），回到起点
- 原地转 360 度

用卷尺量实际终点偏差，对比 `odometry.py` 输出的 (x, y, theta)。这一步目的是验证 kinematics 代码本身没 bug，不是在测 drift——如果偏差离谱（比如方向完全反了），说明 ENCODER_SIGN 或 MOTOR_MAP 还有错，不要急着进 Week4。

### 5. 集成到 can_bridge_node.py

确认 1-4 都没问题后，把 `OdometryEstimator` 接入 `can_bridge_node.py`：
- 收到 0x200+0x201 后调用 `odo.update()`
- 发布 `nav_msgs/Odometry` topic
- 发布 odom→base_link TF

### 6. Week4 drift 实验（前置条件：1-5 全部完成）

设计重复轨迹（直线 1m 来回、正方形、原地转 N 圈），跑 10+ 次，记录每次 odometry 输出的终点 pose。统计 translational drift 和 heading drift 的分布，作为 motion uncertainty 的量化依据。

## 注意

- `ENCODER_CPR=2800` 是理论值，做完任务 3 之前不要拿 drift 数据下结论
- dt 要用 CAN 帧实际到达时间戳算，不要假设固定 20ms
- 所有代码改动完成后更新 PROJECT_STATE.md

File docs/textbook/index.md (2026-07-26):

# SummerSLAM Engineering Notes

**Building an X-Drive SLAM Rover, One Layer at a Time**

:::{admonition} Notes status: Weeks 1-3 first drafts, Weeks 4-6 outlined
:class: status status-progress

The site structure and evidence map are live. Weeks 1-2 form one platform and
programming narrative, and Week 3 begins the concept-focused localization
work. Weeks 4-6 remain outlines and will be expanded in order. A chapter's
engineering status describes the rover, not the completeness of the written
notes.
:::

SummerSLAM connects an STM32F411 motor-control layer to a Raspberry Pi 4B
running ROS 2 Jazzy. Encoder odometry, calibrated ultrasonic measurements, and
probabilistic localization are added one measurable layer at a time. The
repository keeps firmware, robot-side software, raw data, and the reasoning
behind calibration decisions together.

```{figure} _static/system-architecture.svg
:alt: SummerSLAM system architecture from the PS2 controller and ROS 2 computer through CAN to the STM32, drive base, encoders, and ultrasonic sensors.
:class: architecture-figure
:align: center

The Week 1-6 system boundary. Commands move left to right; telemetry returns
to the ROS 2 computer for estimation.
```

## Six-week roadmap

| Week | Topic | Chapter status | Engineering evidence |
| --- | --- | --- | --- |
| {doc}`1-2 <weeks/week1_platform>` | Platform bring-up and programming | First draft | Motors, encoders, CAN transport, and PS2 control verified; tutorials and build evidence remain to be added |
| {doc}`3 <weeks/week3_odometry>` | X-drive kinematics and encoder odometry | First draft | Encoder map, signs, CPR, frame convention, and estimator implemented |
| {doc}`4 <weeks/week4_motion_uncertainty>` | Ground-truth calibration and motion uncertainty | Outline | Translation scale identified; full repeatability campaign remains pending |
| {doc}`5 <weeks/week5_ultrasonic>` | Ultrasonic sensing and measurement model | Outline | Bench calibration and map validation completed |
| {doc}`6 <weeks/week6_mcl>` | Monte Carlo Localization | In progress | Design is on `main`; implementation remains on `week6-mcl` |

## How to use these notes

Read the chapters in order if you are reproducing the rover. Each chapter will
grow toward the same contract:

1. Define the physical or probabilistic model.
2. State the hardware and software prerequisites.
3. Link the exact implementation and input data.
4. Describe the experiment and expected observations.
5. Separate verified results from hypotheses and remaining work.
6. Preserve failures and repairs as reproducible debugging evidence.

This is an engineering process journal, not a general robotics textbook. It
explains what I chose, what failed, what I measured, and what I would change so
that a reader can adapt the process instead of treating one parts list as the
only correct build.

The source repository is
[Tuomaaa/XDriveSLAMRover](https://github.com/Tuomaaa/XDriveSLAMRover).
Project status and decisions are tracked in
[`PROJECT_STATE.md`](https://github.com/Tuomaaa/XDriveSLAMRover/blob/main/PROJECT_STATE.md).

```{toctree}
:hidden:
:maxdepth: 2
:caption: Weeks 1-6

weeks/week1_platform
weeks/week3_odometry
weeks/week4_motion_uncertainty
weeks/week5_ultrasonic
weeks/week6_mcl
```

```{toctree}
:hidden:
:maxdepth: 2
:caption: Appendices

appendices/reproduction_environment
appendices/can_protocol
appendices/calibration_data
appendices/debugging_safety
```

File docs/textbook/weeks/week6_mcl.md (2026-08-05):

# Week 6 — Monte Carlo Localization

:::{admonition} Chapter status: In progress
:class: status status-progress

The particle filter, convergence test, CSV log contract, and offline replay
tool are implemented and pass all tests on the `week6-mcl` branch. The
implementation and synthetic replay evidence must be merged and reverified
before this chapter can claim completion.
:::

:::{admonition} File guide
:class: tip

**Core algorithm — read this first**

- [`mcl.py`](https://github.com/Tuomaaa/XDriveSLAMRover/blob/week6-mcl/ros2_ws/src/mcl.py) — particle filter: predict (body-frame motion model), update (measurement scoring), low-variance resample, weighted circular-mean estimate

**Recommended — Week 5 dependencies**

- [`measurement_model.py`](https://github.com/Tuomaaa/XDriveSLAMRover/blob/main/ros2_ws/src/measurement_model.py) — `BeamModel` that scores each particle
- [`map_model.py`](https://github.com/Tuomaaa/XDriveSLAMRover/blob/main/ros2_ws/src/map_model.py) — `RectMap` that computes expected ranges

**Infrastructure — safe to skip**

- `mcl_log.py` — CSV column contract between logger and replay
- `mcl_offline.py` — replay loop and GIF rendering

**Tests — safe to skip**

- `mcl_test.py` — synthetic convergence test (L-path) and heading tracking test (arc)
:::

## From range scoring to pose estimation

Week 5 built a log-likelihood function that scores a candidate pose against
measured ranges and a rectangular map. That function answers one question:
"given these two sensor readings, how plausible is this pose?" It does not
answer the question a moving robot needs: "where am I?"

Monte Carlo Localization (MCL) maintains a cloud of weighted guesses — called
particles — and uses the likelihood function to prune bad guesses each cycle.
The surviving particles concentrate around the true pose over time, even as
encoder drift pushes dead reckoning away from reality.

This chapter implements the standard MCL algorithm from Probabilistic Robotics
Chapter 8, with one structural change: the motion model operates in the
body frame instead of the textbook's rot1/trans/rot2 decomposition. It then
validates the filter against dead reckoning in a synthetic convergence test.

## Prerequisites

- Body-frame odometry increments from Week 3/4
- The calibrated multi-sensor likelihood from Week 5
  (`BeamModel` and `RectMap`)
- A rectangular map and measured sensor extrinsics
- A deterministic random seed for replayable tests

## How to read the repository

| Order | File | What to read |
| ---: | --- | --- |
| 1 | [`mcl.py` constants and defaults](https://github.com/Tuomaaa/XDriveSLAMRover/blob/week6-mcl/ros2_ws/src/mcl.py#L38) | The Week 5 calibration values carried forward: `SIGMA_HIT`, `BEAM_WEIGHTS`, `SENSOR_CONFIGS`, `MAP_BOUNDS`. Read these before the class. |
| 2 | [`MCL.__init__` and `initialize`](https://github.com/Tuomaaa/XDriveSLAMRover/blob/week6-mcl/ros2_ws/src/mcl.py#L87) | Constructor parameters, particle array layout, and the Gaussian scatter. |
| 3 | [`MCL.predict`](https://github.com/Tuomaaa/XDriveSLAMRover/blob/week6-mcl/ros2_ws/src/mcl.py#L117) | Body-frame motion model with noise floor. Compare this to Probabilistic Robotics Table 5.6 and note the differences. |
| 4 | [`MCL.update`](https://github.com/Tuomaaa/XDriveSLAMRover/blob/week6-mcl/ros2_ws/src/mcl.py#L155) | Measurement update: score each particle with the beam model, then resample. |
| 5 | [`MCL._low_variance_resample`](https://github.com/Tuomaaa/XDriveSLAMRover/blob/week6-mcl/ros2_ws/src/mcl.py#L193) | Probabilistic Robotics Table 4.4 implemented in numpy. |
| 6 | [`mcl_test.py`](https://github.com/Tuomaaa/XDriveSLAMRover/blob/week6-mcl/ros2_ws/src/mcl_test.py) | Convergence test: simulated L-path with injected yaw drift, MCL vs dead reckoning. |
| 7 | [`mcl_log.py`](https://github.com/Tuomaaa/XDriveSLAMRover/blob/week6-mcl/ros2_ws/src/mcl_log.py) | The shared CSV contract between the ROS node logger and the offline replay. |
| 8 | [`mcl_offline.py`](https://github.com/Tuomaaa/XDriveSLAMRover/blob/week6-mcl/ros2_ws/src/mcl_offline.py) | Replay a recorded CSV through the filter and render a GIF. |

## Particle state and initialization

The MCL class holds two arrays. `particles` is an $(N, 3)$ numpy array where
each row stores $(x, y, \theta)$. `weights` is an $(N,)$ array that sums to
1.0.

```python
# mcl.py — MCL constructor (abbreviated)
self.particles = np.zeros((self.num_particles, 3))
self.weights = np.full(self.num_particles, 1.0 / self.num_particles)
```

`initialize()` scatters particles as a Gaussian cloud around a known starting
pose. Global localization (uniform scatter over the entire map) is not
implemented. The rover starts at a measured position, so a tight cloud is
appropriate.

```python
# mcl.py — initialize()
self.particles[:, 0] = self._rng.normal(x, xy_spread, count)
self.particles[:, 1] = self._rng.normal(y, xy_spread, count)
self.particles[:, 2] = _wrap_angle(
    self._rng.normal(theta, theta_spread, count))
self._clamp_to_map()
self.weights = np.full(count, 1.0 / count)
```

`_clamp_to_map()` clips every particle to the map rectangle. A particle
outside the walls has no meaningful expected range and lingers on the
`w_rand` floor indefinitely. Clamping keeps every particle scoreable.

### The weighted pose estimate

`estimate()` computes the weighted mean of all particles. The $\theta$
component uses a circular mean:

$$\hat{\theta} = \text{atan2}\!\left(\sum_i w_i \sin\theta_i,\;
\sum_i w_i \cos\theta_i\right)$$

A scalar mean of headings near $\pm\pi$ averages to zero. Two
particles at $+179°$ and $-179°$ must produce an estimate near $180°$.
The circular mean handles this correctly.

```python
# mcl.py — estimate()
sin_sum = float(np.sum(self.weights * np.sin(self.particles[:, 2])))
cos_sum = float(np.sum(self.weights * np.cos(self.particles[:, 2])))
return x, y, math.atan2(sin_sum, cos_sum)
```

After resampling, all weights are uniform ($1/N$). The weighted mean then
becomes an unweighted mean. It also assumes the cloud is unimodal. A cloud
with two separated clusters produces a pose between them.

## Holonomic body-frame motion update

### Why the textbook model does not fit

Probabilistic Robotics Table 5.6 splits each odometry step into three
phases: an initial rotation (rot1), a translation, and a final rotation
(rot2). This decomposition assumes that the robot must turn to face its
direction of travel. An X-drive rover can strafe sideways with zero heading
change. A pure lateral move has zero translation in the rot1/trans/rot2
sense, so the model injects zero noise — a wrong result for a step that
moved 200 mm.

SummerSLAM replaces rot1/trans/rot2 with direct body-frame perturbation.
The filter receives $(dx, dy, d\theta)$ in the robot's own frame and adds
Gaussian noise to each component.

### The predict method

Each call to `predict(dx_body, dy_body, dtheta)` does four things for
every particle:

1. Compute noise standard deviations from the step size.
2. Add Gaussian noise to the body-frame delta.
3. Rotate the noisy delta into the world frame using that particle's heading.
4. Clamp the result inside the map.

```python
# mcl.py — predict() (core)
distance = math.hypot(dx_body, dy_body)
turned = abs(dtheta)
sigma_trans = max(a_trans_trans * distance + a_trans_rot * turned,
                  SIGMA_TRANS_FLOOR)
sigma_rot = max(a_rot_trans * distance + a_rot_rot * turned,
                SIGMA_ROT_FLOOR)

noisy_dx = dx_body + self._rng.normal(0.0, sigma_trans, count)
noisy_dy = dy_body + self._rng.normal(0.0, sigma_trans, count)
noisy_dtheta = dtheta + self._rng.normal(0.0, sigma_rot, count)

heading = self.particles[:, 2].copy()
cos_h = np.cos(heading)
sin_h = np.sin(heading)

self.particles[:, 0] += noisy_dx * cos_h - noisy_dy * sin_h
self.particles[:, 1] += noisy_dx * sin_h + noisy_dy * cos_h
self.particles[:, 2] = _wrap_angle(heading + noisy_dtheta)
```

Step 3 is the critical line. Each particle rotates the noisy delta by *its
own* heading. Particles that disagree about which way they face end up in
different places. The measurement update then prunes the ones that land in
poses inconsistent with the sensor readings.

### The alpha parameters

The four alpha values control how much noise each step injects:

| Alpha | Meaning |
| --- | --- |
| `a_trans_trans` | Translation noise from translation distance |
| `a_trans_rot` | Translation noise from rotation angle |
| `a_rot_trans` | Rotation noise from translation distance |
| `a_rot_rot` | Rotation noise from rotation angle |

The alphas keep the same *role* as Probabilistic Robotics Table 5.6. The
*numbers* are different. The textbook multiplies squared deltas to produce a
variance. This implementation multiplies un-squared deltas to produce a
standard deviation directly. Do not carry Table 5.6 values over.

Default values are `(0.05, 0.01, 0.01, 0.05)`. The convergence test uses
`(0.25, 0.05, 0.05, 0.15)` because its simulated odometry is more corrupt
than the real chassis.

### The noise floor

A strictly proportional model injects zero noise when the rover is parked.
The measurement update resamples every cycle regardless of motion. With no
noise to replenish diversity, 500 particles collapse to a single distinct
particle within about 1.5 seconds of standstill.

Two constants set the floor:

```python
SIGMA_TRANS_FLOOR = 0.001   # metres per step
SIGMA_ROT_FLOOR = 0.010     # radians per step
```

The rotational floor is the more important of the two. Heading is the
weakly-observed dimension (explained in the final section). Resampling
impoverishes it first. Calibrated 2026-07-22 against a 60-second synthetic
wander:

- At `SIGMA_ROT_FLOOR = 0.002`: heading spread collapsed to 0.4° within
  7 seconds. Heading error grew to 28.3° by 52 seconds. Position RMS
  reached 10.2 cm.
- At `SIGMA_ROT_FLOOR = 0.010`: heading spread held near 1°. Heading error
  stayed within 2°. Position RMS dropped to 1.0 cm.

The value 0.010 sits mid-plateau. Behaviour is flat from 0.005 to 0.020
and degrades again by 0.040.

## Measurement update in log space

`update()` reweights every particle against the current sensor readings,
then resamples. The flow has four steps.

### 1. Score each particle

For each particle, the beam model computes a log-likelihood that the
measured ranges came from that pose:

```python
# mcl.py — update() scoring loop
for index in range(self.num_particles):
    pose = (float(self.particles[index, 0]),
            float(self.particles[index, 1]),
            float(self.particles[index, 2]))
    log_weights[index] = self.beam_model.total_log_likelihood(
        measurements, pose, self.rect_map, self.sensor_configs)
```

This is the bridge to Week 5. `total_log_likelihood` computes the expected
range from each sensor at the candidate pose, scores the actual reading
against it using the calibrated beam model, and sums the log-likelihoods.

### 2. Handle None sensors

A sensor with no valid echo this cycle passes as `None`. If both sensors
are `None`, the update is a no-op. With nothing observed, resampling on
uniform weights destroys diversity for no gain.

### 3. Exponentiate safely

The raw log-likelihoods run to several hundred negative. A direct `exp()`
underflows to all zeros. The standard fix is to subtract the maximum
before exponentiating:

```python
shifted = log_weights - np.max(log_weights[finite])
weights = np.exp(shifted)
self.weights = weights / float(np.sum(weights))
```

The highest-scoring particle gets weight `exp(0) = 1`. All others get
values relative to that maximum. The absolute magnitude cancels in
normalization.

### 4. Resample

After normalization, `_low_variance_resample()` rebuilds the particle set.

## Low-variance resampling

The resampler implements Probabilistic Robotics Table 4.4. It draws one
random offset $r \in [0, 1/N)$, then walks through the cumulative weight
distribution in steps of $1/N$.

```python
# mcl.py — _low_variance_resample()
positions = (self._rng.uniform(0.0, 1.0 / count)
             + np.arange(count) / count)

cumulative = np.cumsum(self.weights)
cumulative[-1] = 1.0
indexes = np.searchsorted(cumulative, positions)
np.clip(indexes, 0, count - 1, out=indexes)

self.particles = self.particles[indexes]
self.weights = np.full(count, 1.0 / count)
```

A particle of weight $w$ receives either $\lfloor wN \rfloor$ or
$\lceil wN \rceil$ copies. Multinomial resampling gives a binomial spread
around that number instead. Low-variance resampling is $O(N)$ and
preserves particle diversity better.

After resampling, all weights reset to $1/N$. The cloud's information now
lives in particle density: more copies of a pose means more weight.

## CSV logging and offline replay

### The shared log format

`mcl_log.py` defines the CSV contract that the ROS node writes and the
offline replay reads. One row per ultrasonic frame (~8 Hz), carrying the
latest odometry pose. One row is one MCL predict+update cycle.

```
timestamp_s, odom_x, odom_y, odom_theta, right_mm, back_mm, right_valid, back_valid
```

Ranges are in millimetres in the CSV to match the CAN payload.
`read_log()` converts to metres for the filter. A sensor whose validity bit
is clear becomes `None` so the filter skips it instead of scoring against the
0xFFFF timeout sentinel.

The module uses only the standard library. The ROS node imports it on the
Pi without pulling in numpy or matplotlib.

### Body-frame delta computation

The log stores world-frame odometry poses. The filter consumes body-frame
deltas. `body_frame_delta()` converts between the two:

```python
# mcl_offline.py — body_frame_delta()
dx_world = current[0] - previous[0]
dy_world = current[1] - previous[1]
cos_t = math.cos(previous[2])
sin_t = math.sin(previous[2])
dtheta = current[2] - previous[2]
return (
    dx_world * cos_t + dy_world * sin_t,
    -dx_world * sin_t + dy_world * cos_t,
    math.atan2(math.sin(dtheta), math.cos(dtheta)),
)
```

Rotating the world displacement by $-\theta_{\text{prev}}$ undoes the heading
it was expressed in. The result is the step the robot felt in its own frame.

### Replay loop

`replay()` iterates through the log. For each row after the first (which
establishes the odometry origin), it computes the body-frame delta, calls
`predict()`, then calls `update()` with the range readings. Each step
records a frame for the animation.

### GIF animation

`render()` produces a GIF with matplotlib:

- Gray rectangle: map boundary
- Blue dots: particles (the cloud)
- Red dot and arrow: MCL estimated pose and heading
- Green dot: dead-reckoning pose
- Orange lines: sensor beams from the estimate to the measured range

A beam that stops short of the wall means the estimate is too far from
that wall. A beam that overshoots means the estimate is too close.

## Convergence test: MCL vs dead reckoning

`mcl_test.py` runs two hardware-free tests that prove the filter works.

### The L-path test

A simulated rover drives an L-shaped path inside the KT-board map: 300 mm
forward (+x), then 300 mm left (+y), at 5 mm per cycle. The odometry handed
to the filter is corrupted with 3% scale error and a steady yaw bias of
0.002 rad per step. The range readings carry Week 5 calibrated noise.

Results with a fixed random seed:

```
true       x=0.600 y=0.600
dead-reck  x=0.539 y=0.603  error=6.2cm
mcl        x=0.580 y=0.588  error=2.3cm  theta=+12.6deg
```

MCL error is 2.3 cm. Dead-reckoning error is 6.2 cm. The filter beats
raw integration by a factor of 2.7.

### Why MCL error is 2.3 cm instead of zero

The filter ends up at $\theta = +12.6°$ when the truth is $0°$. That is
the injected yaw bias (0.002 rad × 120 steps = 13.8°) passing through
almost uncorrected. The reason is heading observability, explained below.

A wrong heading biases position. The filter reads each range as
$d/\cos(\theta)$ and places itself a fraction short of each wall. At
12.6° of heading error and these distances, that fraction is about
1.2 cm per axis — consistent with the 2.3 cm observed.

### The arc test

A second test drives the rover along a half-circle arc to exercise heading
under sustained rotation. Final heading error stays within 10°. Position
error stays within 3 cm.

## Limits of heading observability

This section explains the filter's sharpest limitation. Position (x, y) is
directly observable through range measurements. Heading ($\theta$) is not.

Two orthogonal beams in a rectangular room measure distances to walls. A
small heading rotation $\theta$ changes an expected range only as
$1/\cos(\theta)$, a second-order effect. At 5° of heading error, the
expected range changes by 0.4%. The HC-SR04's ~3 mm noise swamps that
signal.

The consequence: the filter can correct x and y drift within a centimetre.
It cannot correct heading drift. An uncorrected heading error of $\theta$
makes the filter place itself $d(1 - \cos\theta)$ away from the true wall
distance. At 12.6° and typical distances, that is about 1.2 cm.

The fix is a third sensor at a different angle, or the Week 11 IMU. A
parameter change cannot create heading information that the sensor geometry
does not provide.

### The noise floor keeps the problem bounded

Without the rotational noise floor, the cloud commits to a heading within
seconds and the error grows without bound. The floor (`SIGMA_ROT_FLOOR =
0.010 rad/step`) maintains enough heading diversity that the filter can
slowly track heading changes through the second-order range signal. It
cannot eliminate heading error, but it prevents runaway drift.

(mcl-design-corrections)=
## Design corrections

### Holonomic motion model

The standard rot1/trans/rot2 decomposition (Probabilistic Robotics Table
5.6) assumes a platform that turns to translate. This chassis is holonomic.
SummerSLAM perturbs body-frame $dx$, $dy$, and $d\theta$ directly so that
lateral X-drive motion remains representable.

### Alpha parameter scaling

The textbook alphas multiply *squared* deltas to produce a variance. This
implementation multiplies *un-squared* deltas to produce a standard
deviation. The numerical values are not comparable.

### Noise floor necessity

The textbook does not discuss a noise floor because differential-drive
robots rarely park during a filter cycle. An X-drive rover with two
ultrasonic sensors at 8 Hz has many cycles of near-zero motion. Without
a floor the cloud collapses.

## Source and evidence

- [`mcl.py` on `week6-mcl`](https://github.com/Tuomaaa/XDriveSLAMRover/blob/week6-mcl/ros2_ws/src/mcl.py) — particle filter core
- [`mcl_test.py` on `week6-mcl`](https://github.com/Tuomaaa/XDriveSLAMRover/blob/week6-mcl/ros2_ws/src/mcl_test.py) — convergence and heading tracking tests
- [`mcl_log.py` on `week6-mcl`](https://github.com/Tuomaaa/XDriveSLAMRover/blob/week6-mcl/ros2_ws/src/mcl_log.py) — shared CSV contract
- [`mcl_offline.py` on `week6-mcl`](https://github.com/Tuomaaa/XDriveSLAMRover/blob/week6-mcl/ros2_ws/src/mcl_offline.py) — replay and GIF rendering
- [MCL design specification](https://github.com/Tuomaaa/XDriveSLAMRover/blob/main/docs/superpowers/specs/2026-07-22-mcl-particle-filter-design.md) — the original design document
- [MCL implementation plan](https://github.com/Tuomaaa/XDriveSLAMRover/blob/main/docs/superpowers/plans/2026-07-22-mcl-particle-filter.md) — task-by-task build plan with expected outputs

## Verification state

| Item | Status |
| --- | --- |
| Unit tests (`mcl.py _run_tests`) | Pass on `week6-mcl`, 10 tests |
| L-path convergence (`mcl_test.py`) | Pass: 2.3 cm MCL vs 6.2 cm dead reckoning |
| Arc heading tracking (`mcl_test.py`) | Pass: heading error < 10°, position error < 3 cm |
| Noise floor calibration | Complete: `SIGMA_ROT_FLOOR = 0.010` verified against synthetic wander |
| Offline replay tests (`mcl_offline.py`) | Pass: body-frame delta and odom-to-map transforms verified |
| CSV log contract (`mcl_log.py`) | Pass: round-trip read/write with valid and invalid sensors |
| Real robot log replay | Not yet captured. Requires Task 6 (CAN bridge logging) and Task 8 (recorded run). |
| Online ROS2 node (`mcl_node.py`) | Deferred until offline replay is validated against real data. |
| Merge to `main` | Pending. |

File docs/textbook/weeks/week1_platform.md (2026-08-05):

# Weeks 1-2 - Build and Program the Rover

:::{admonition} Page scope: hardware build and first bring-up
:class: status status-progress

This chapter explains how I chose the platform, built the rover, and brought up
the first motor, encoder, CAN, and controller paths. It separates tests that
worked on real hardware from later work such as calibrated odometry,
closed-loop speed control, localization, and SLAM.
:::

:::{admonition} File guide
:class: tip

**Core — read these first**

- [`main.c`](https://github.com/Tuomaaa/XDriveSLAMRover/blob/main/stm32/Core/Src/main.c) — motor map (`MotorPosition`), encoder readout, CAN heartbeat, 20 ms control loop
- [`protocol.py`](https://github.com/Tuomaaa/XDriveSLAMRover/blob/main/ros2_ws/src/protocol.py) — CAN message contract between STM32 and Pi

**Recommended**

- [`PS2_Drive_Test.py`](https://github.com/Tuomaaa/XDriveSLAMRover/blob/main/ros2_ws/src/PS2_Drive_Test.py) — controller input to motor commands, heartbeat thread
- [`encoder_monitor.py`](https://github.com/Tuomaaa/XDriveSLAMRover/blob/main/ros2_ws/src/encoder_monitor.py) — raw four-wheel encoder display for harness verification

**Infrastructure — safe to skip**

- `mcp2515.c` — MCP2515 SPI driver
- `PS2.py` — PS2 controller GPIO/SPI driver
- `can_interface.py` — SocketCAN wrapper
- `SummerSLAM.ioc`, `CMakePresets.json`, `CMakeLists.txt` — CubeMX configuration and build system
:::

## What I wanted to build

I wanted a platform that another student can understand, rebuild, and change
without copying every part.

The first two weeks had one practical goal: turn a set of mechanical and
electrical parts into a rover that can accept a command and return encoder
data. That required several smaller steps:

1. Choose the wheel layout and frame.
2. Decide what must fit on each deck.
3. Split high-level computing from real-time control.
4. Set up the STM32 pins, timers, and build tools.
5. Test one motor before testing all four.
6. Read all four encoders.
7. Send commands and feedback between the STM32 and Raspberry Pi.
8. Add a hand controller for drive tests.

The final platform uses two printed decks, four omni wheels, a Raspberry Pi 4B,
and an STM32F411. The route was not direct. I first chose an MCU with too few
timers, spent more time on CAN than UART needs, and lost several
boards in two electrical accidents. Those mistakes are part of the build
process, so I include them instead of showing only the final rover.

## Part 1 - Build the hardware

### Why I chose an X-drive

I chose a four-wheel X-drive because it is holonomic. The rover can move
forward, sideways, or diagonally without turning first, and it can also rotate
in place.

Most beginner robots use two-wheel differential drive. That layout is simpler,
but it is also covered by many existing tutorials. The X-drive gave this
project a different motion model and forced me to understand the kinematics
rather than copy a familiar two-wheel solution.

<div class="media-grid media-grid-three">
  <figure>
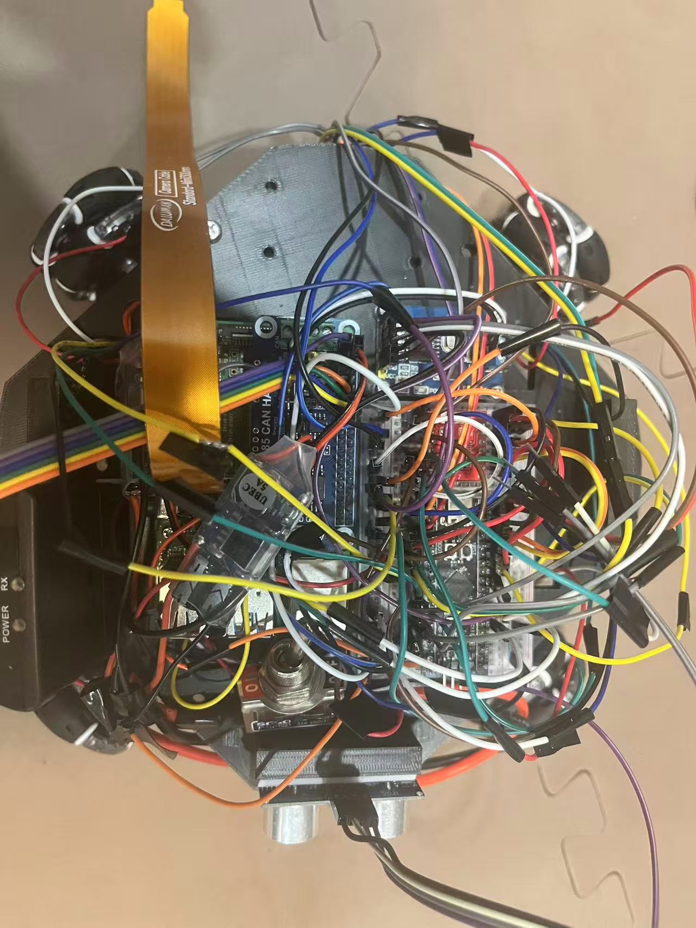
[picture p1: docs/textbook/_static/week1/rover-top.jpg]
Top view of the finished X-drive rover
    
    <figcaption>Top view of the rover.</figcaption>
  </figure>
  <figure>
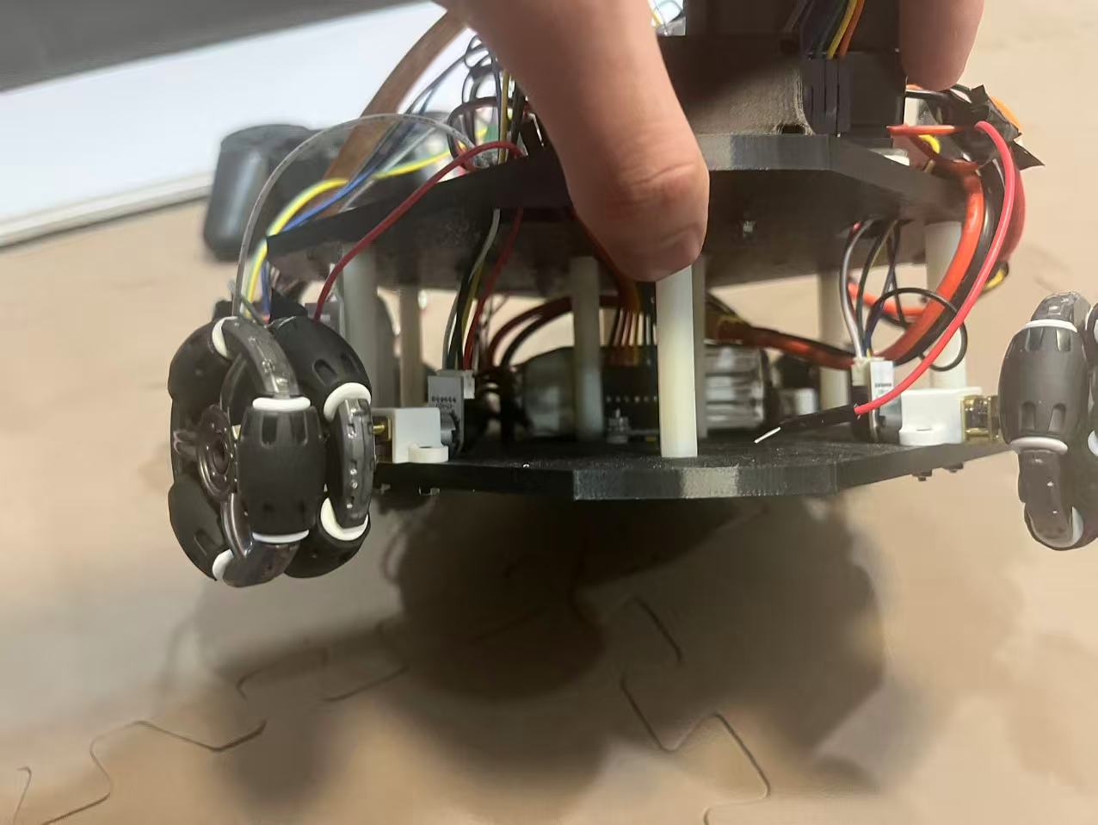
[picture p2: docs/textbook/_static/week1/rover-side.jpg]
Side view of the finished X-drive rover
    
    <figcaption>Side view of the two decks.</figcaption>
  </figure>
  <figure>
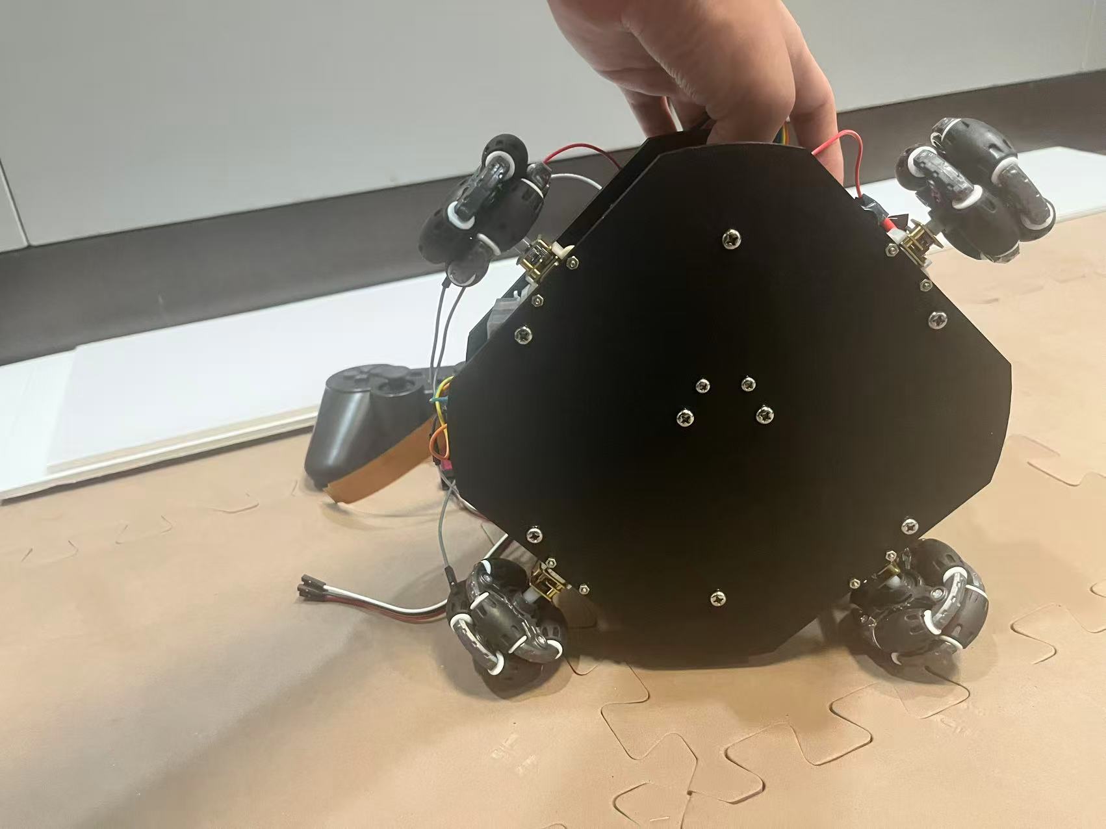
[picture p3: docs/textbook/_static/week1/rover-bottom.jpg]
Bottom view of the X-drive rover
    
    <figcaption>Bottom view with the four motors.</figcaption>
  </figure>
</div>

### Start from a reference

My first mechanical reference was the
[MERL ROSIE project](https://github.com/MERL-Rose-Hulman/MERL-Rose-Hulman.github.io/tree/main).
I used it to understand how a small rover can stack its frame and
electronics. I did not copy its plate shape or part layout.

I chose the simplest frame I was able to make: two matching plates joined by
standoffs. I started with a square, rounded the corners, and sized the plate
around the Raspberry Pi. The exact outline is not important. The plate only
needs to hold the wheels in the correct geometry and leave enough space for
the electronics.

### Design the two plates

I used common M4 screws and nylon standoffs. The two plates are similar, which
keeps the part count simple and makes replacement easier.

<div class="media-grid">
  <figure>
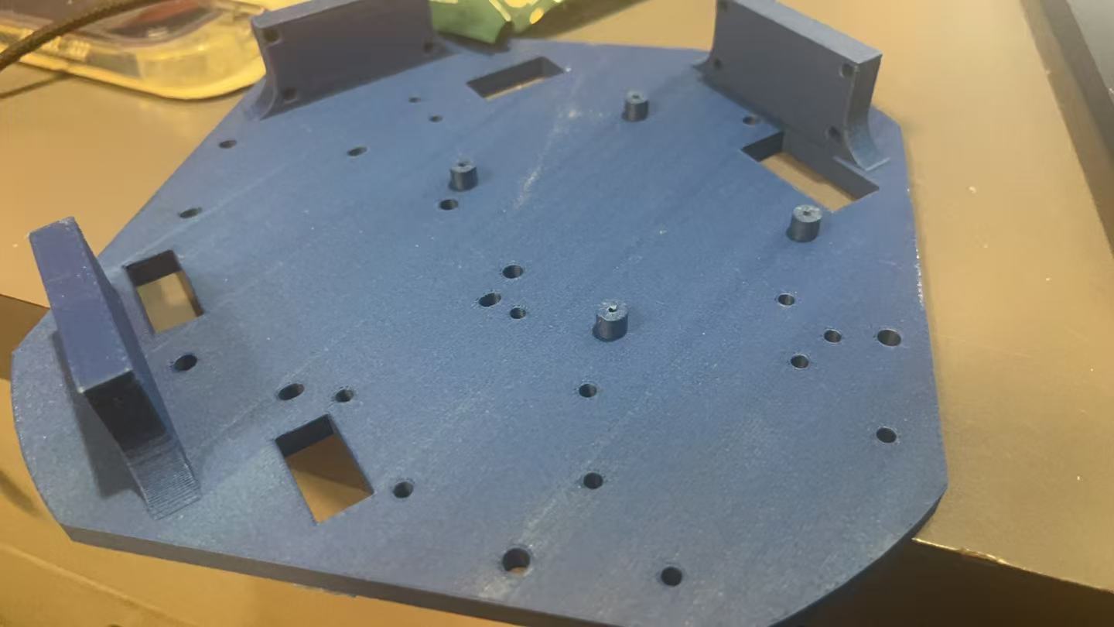
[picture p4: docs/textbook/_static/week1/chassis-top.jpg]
Printed top chassis plate
    
    <figcaption>The printed top plate.</figcaption>
  </figure>
  <figure>
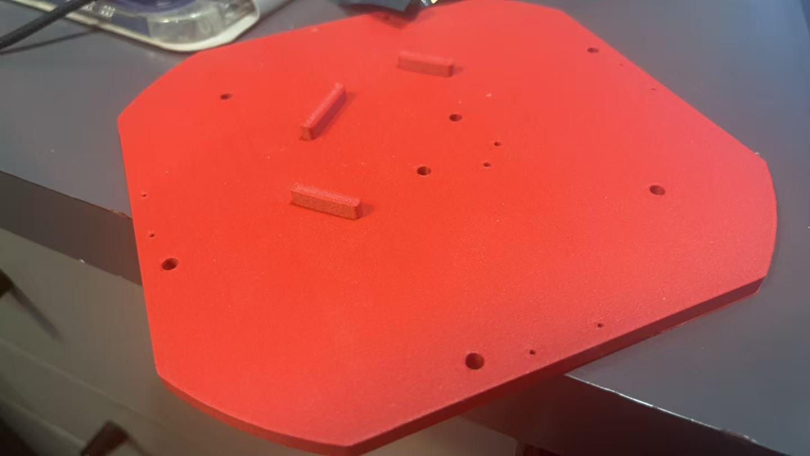
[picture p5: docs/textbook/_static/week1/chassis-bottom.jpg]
Printed bottom chassis plate
    
    <figcaption>The printed bottom plate.</figcaption>
  </figure>
</div>

The clean SolidWorks view shows the plate shape and the main mounting holes.

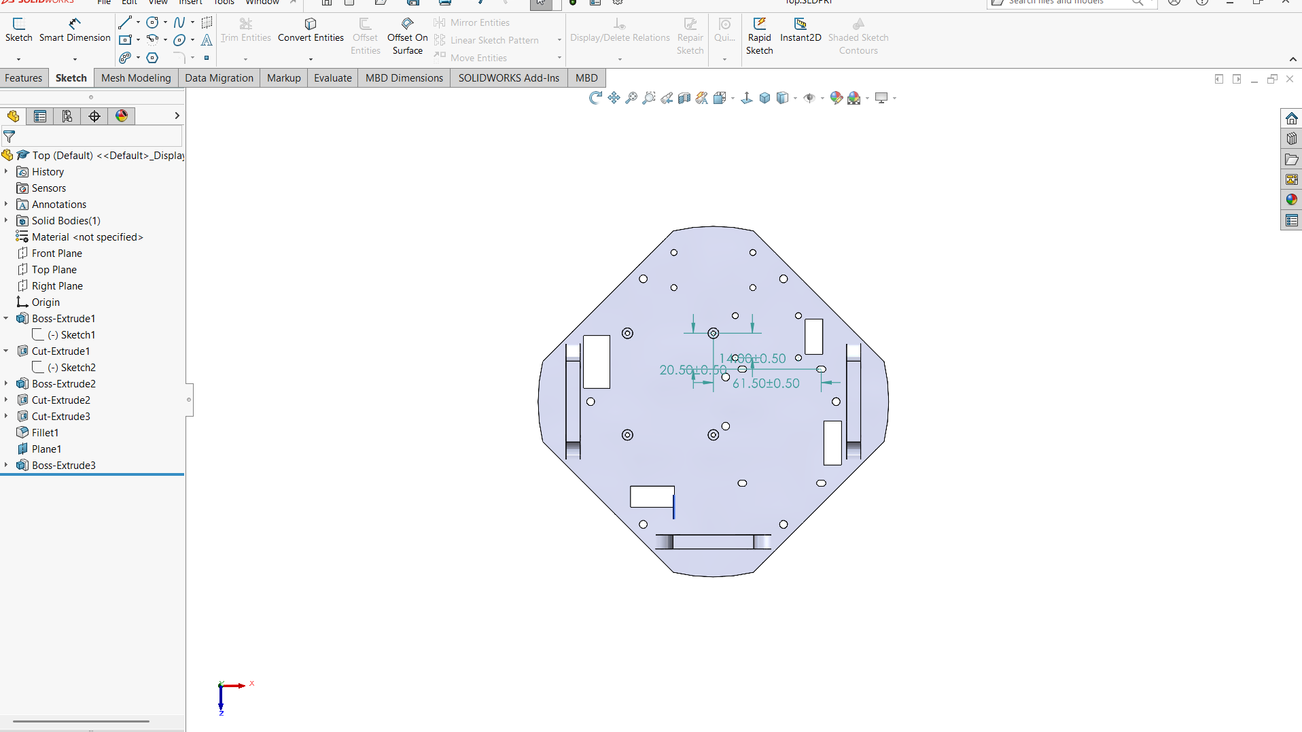
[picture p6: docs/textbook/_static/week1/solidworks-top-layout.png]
:::{figure} ../_static/week1/solidworks-top-layout.png
:alt: Clean SolidWorks top view of the rover plate and mounting holes
:class: chapter-wide-figure
:align: center

SolidWorks top view of the plate.
:::

The next two screenshots show my working sketches. They preserve the real
design history, but too many dimensions are visible at the same time. Use them
as a reference for the CAD process.

<div class="media-grid">
  <figure>
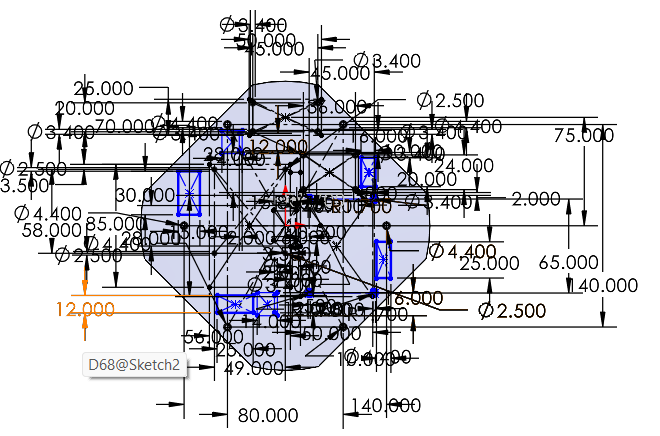
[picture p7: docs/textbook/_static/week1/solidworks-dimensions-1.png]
First SolidWorks working sketch with many dimensions
    
    <figcaption>Working dimension sketch 1.</figcaption>
  </figure>
  <figure>
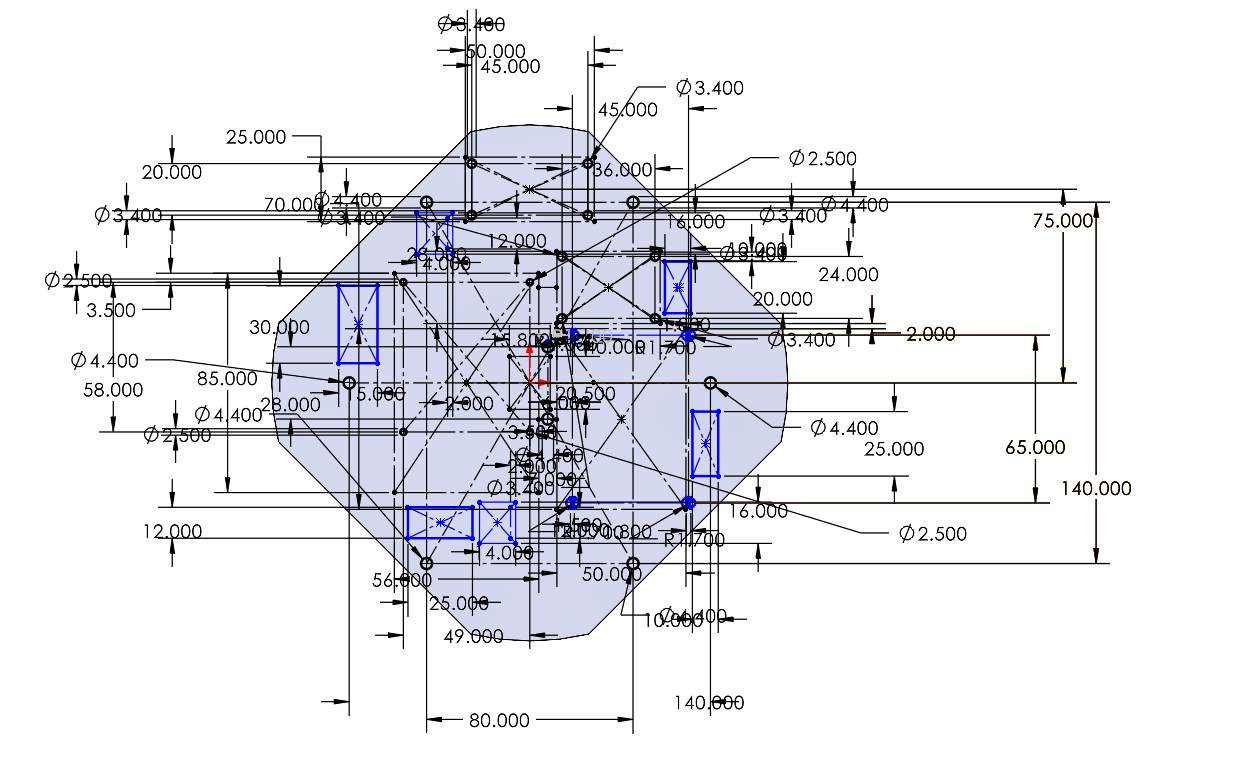
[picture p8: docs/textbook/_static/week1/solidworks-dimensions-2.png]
Second SolidWorks working sketch with many dimensions
    
    <figcaption>Working dimension sketch 2.</figcaption>
  </figure>
</div>

The wheel radius is 25 mm, and the measured center-to-wheel distance used by
the later kinematics is 115 mm.

### Plan the decks around the parts

Before I finished the mounting holes, I listed every part that needs space on
the rover. A plate layout is hard to change after printing, so the physical
BOM must come before the final hole pattern.

The top deck has room for a Raspberry Pi and a breadboard. I also left space
near the corners for HC-SR04 sensors or cameras. The lower deck holds the
battery and IMU near the center. This keeps the heaviest part low and close to
the middle of the rover.

I expected the center position to help the IMU, but I did not measure that
effect during Week 1. Treat it as a design choice.

<div class="media-grid">
  <figure>
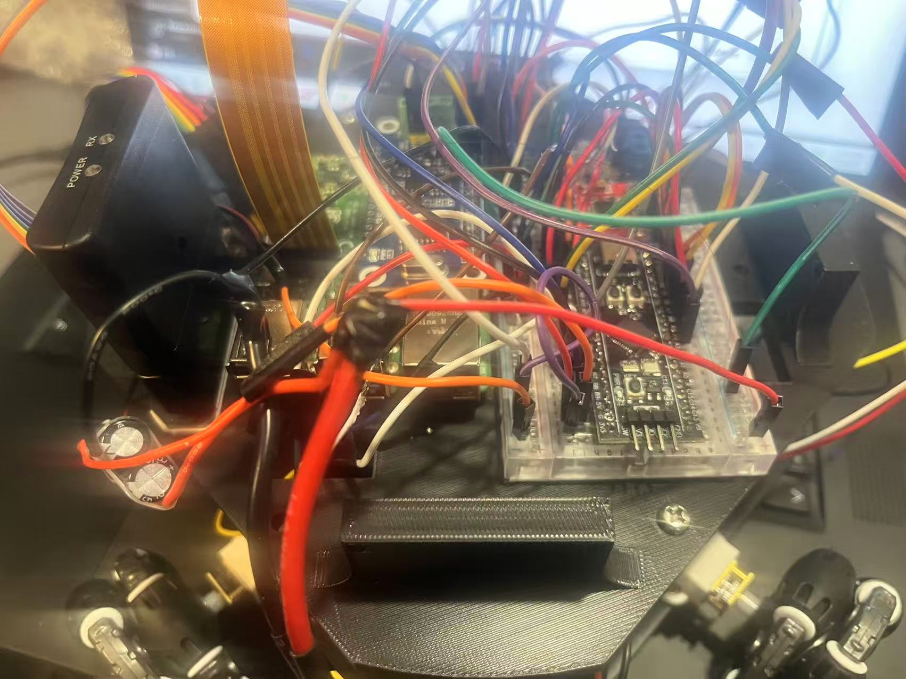
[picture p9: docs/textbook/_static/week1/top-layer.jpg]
Top electronics layer of the rover
    
    <figcaption>Top layer with the Raspberry Pi and wiring.</figcaption>
  </figure>
  <figure>
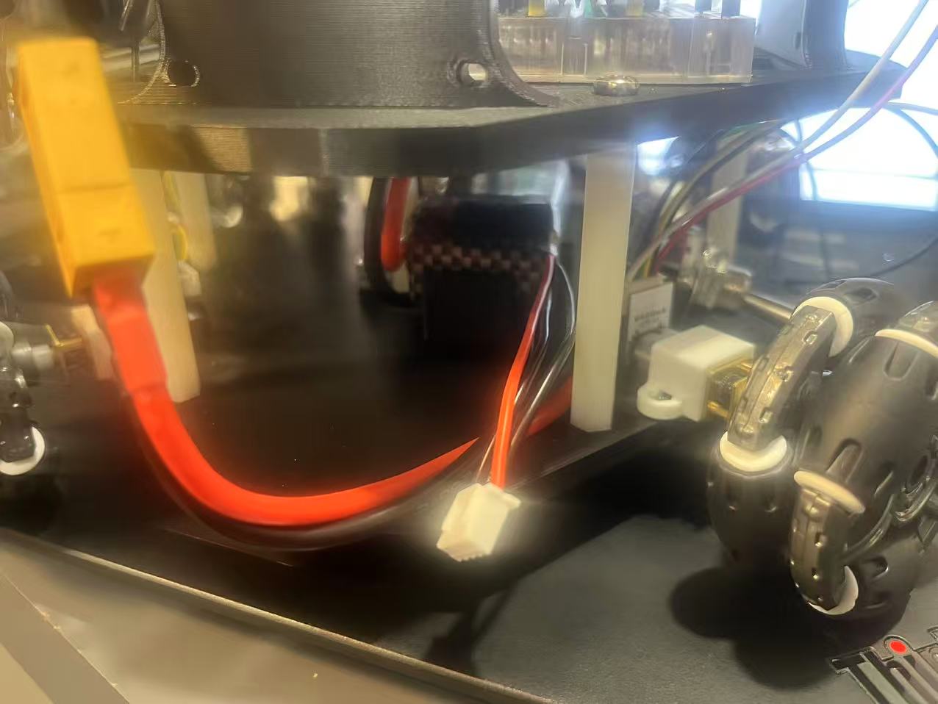
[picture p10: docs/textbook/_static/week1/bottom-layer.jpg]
Bottom power and motor layer of the rover
    
    <figcaption>Bottom layer with power and motor parts.</figcaption>
  </figure>
</div>

### Measure the real boards

The mounting holes took more time than the plate outline. Online drawings were
often missing dimensions, and clone boards did not always match the drawing I
found.

The faster method was to measure the actual board with calipers. I measured the
hole spacing, verified connector clearance, and allowed a little extra space
where the fit did not need to be exact. This method also protects the design
from small changes between sellers.

### Print with useful margin

I expected that the center of the plates can bend, so the first print used
PLA-CF and a high wall count. A later load test suggested that normal PLA is
probably enough.

Even so, I keep some extra strength and empty space. Research robots tend
to gain new sensors, adapter boards, wires, and temporary test hardware. A
plate that fits only the first BOM becomes difficult to use very quickly.

### Split the computing work

The Raspberry Pi runs ROS 2, localization, and later SLAM code. I used a
Raspberry Pi 4B with 8 GB of RAM and a 32 GB microSD card. I recommend at least
32 GB because ROS builds, recorded data, and visual SLAM images can use a large
amount of storage.

Linux on the Pi is not the best place for exact motor and encoder timing. I
therefore used a microcontroller for the real-time layer:

- four PWM motor outputs
- four hardware encoder inputs
- eight motor direction pins
- CAN messages
- heartbeat safety
- sensor timing

I chose STM32 because the boards are small, fast, inexpensive, and have useful
hardware timers. The main cost is setup time: the toolchain is less friendly
than many Arduino-style boards, and flashing normally needs an ST-Link.

Another MCU can work. The important step is to count its timers, channels,
alternate pin functions, and GPIO before buying it.

### The timer mistake

I first bought an STM32F103 Blue Pill without making a full timer table. The
design needs one timer with four PWM channels and four more timers for the four
encoders. In total, I needed five suitable timers.

The F103 board I chose did not fit that plan, so I changed to an
STM32F411CEU6 Black Pill.

| Job | Final timer |
| --- | --- |
| Four motor PWM channels | TIM1 |
| Front-left encoder | TIM2 |
| Front-right encoder | TIM3 |
| Rear encoder 1 | TIM4 |
| Rear encoder 2 | TIM5 |

A one-page peripheral table before buying the MCU prevents this mistake.

### Why I used CAN

The Raspberry Pi and STM32 need a communication link. I chose CAN because I
wanted experience with the message-based communication used in cars.

The Raspberry Pi uses a Waveshare CAN HAT. The STM32 side uses an MCP2515 and a
TJA1050. The MCP2515 is the CAN controller and talks to the STM32 over SPI. The
TJA1050 is the transceiver that drives the physical CAN bus.

The STM32F411 does not contain a CAN controller, so this choice added another
chip, another clock setting, and more driver code. For a short point-to-point
link between one Pi and one MCU, UART is much easier and fast enough.
I recommend CAN only when learning CAN or adding more bus nodes is also
part of the project.

### Main parts

The table gives the main parts and the reason each one exists. Exact sellers
can change, so the electrical role matters more than one product link.

| Part | Role in this rover |
| --- | --- |
| Raspberry Pi 4B, 8 GB | ROS 2, localization, and SLAM computer |
| 32 GB microSD | Operating system, builds, logs, and data |
| STM32F411CEU6 Black Pill | Real-time motor, encoder, CAN, and sensor control |
| Four GA12-N20 encoder motors | Wheel drive and encoder feedback |
| Four 50 mm omni wheels | Holonomic X-drive motion |
| Two TB6612 modules | Four motor-driver channels |
| MCP2515 plus TJA1050 module | STM32-side CAN controller and transceiver |
| Waveshare CAN HAT | Raspberry Pi-side CAN interface |
| MPU6050 | IMU used for later sensing work |
| 3S 1500 mAh 35C LiPo | Main battery |
| 5 V, 5 A UBEC modules | Low-voltage power |
| ST-Link | STM32 programming and debug |
| PS2-style controller | Manual drive input |

<div class="media-grid parts-grid">
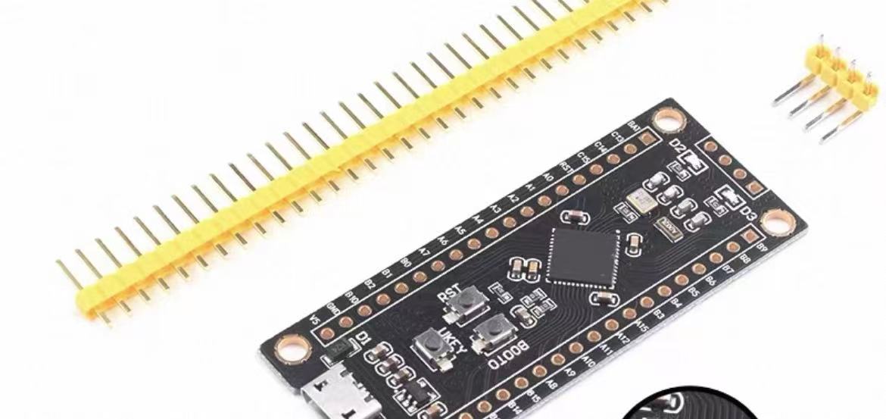
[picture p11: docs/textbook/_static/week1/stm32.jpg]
STM32F411 Black Pill board
  <figure><figcaption>STM32F411 board</figcaption></figure>
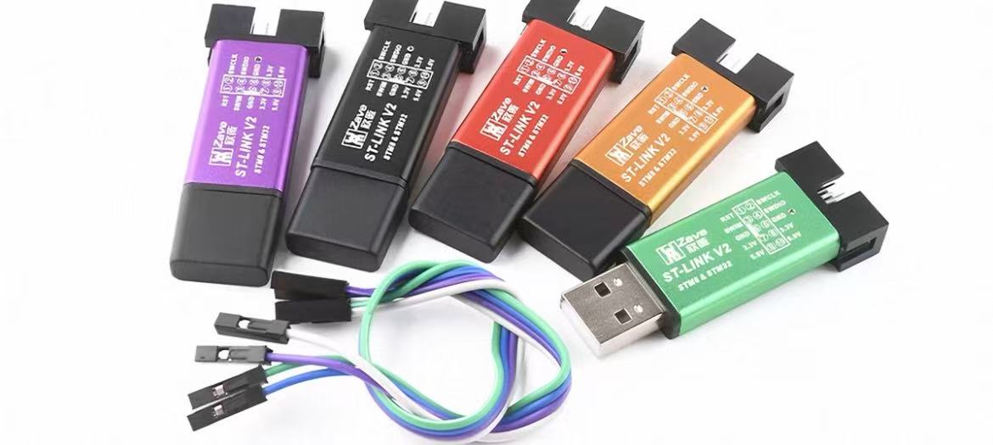
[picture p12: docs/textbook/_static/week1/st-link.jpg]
ST-Link programmers
  <figure><figcaption>ST-Link</figcaption></figure>
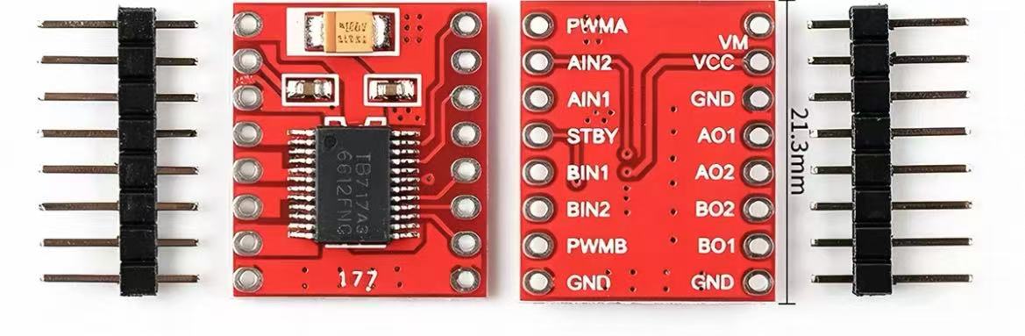
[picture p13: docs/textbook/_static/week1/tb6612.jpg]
TB6612 motor driver board
  <figure><figcaption>TB6612 driver</figcaption></figure>
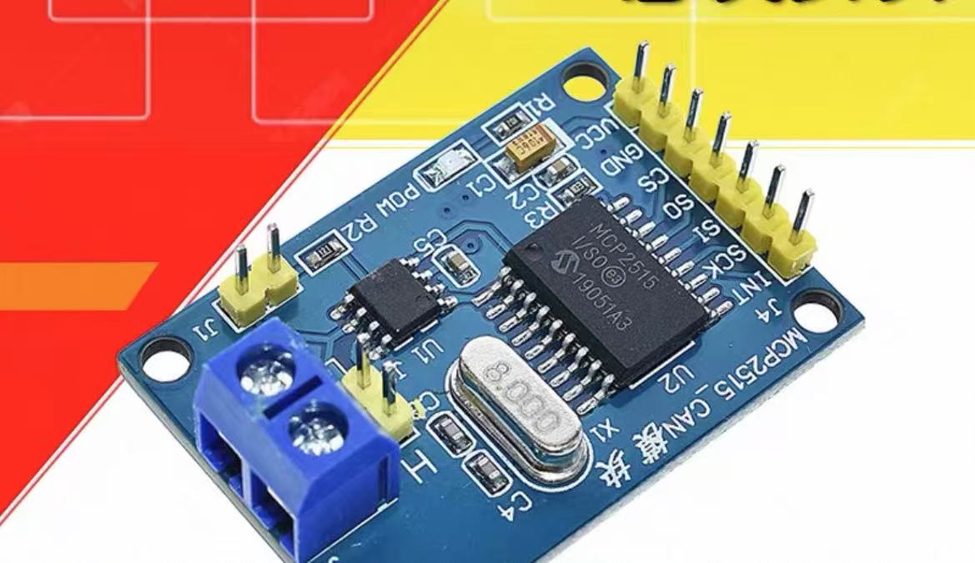
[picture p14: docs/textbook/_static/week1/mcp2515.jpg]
MCP2515 CAN module
  <figure><figcaption>MCP2515 CAN module</figcaption></figure>
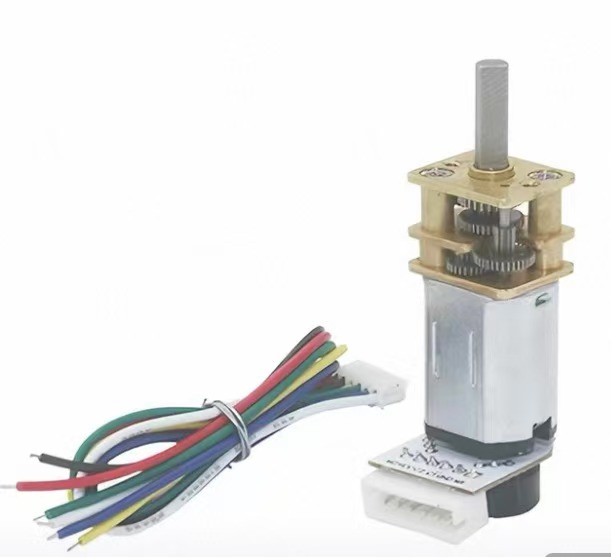
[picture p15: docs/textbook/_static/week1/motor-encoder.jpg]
GA12-N20 motor with encoder
  <figure><figcaption>Motor and encoder</figcaption></figure>
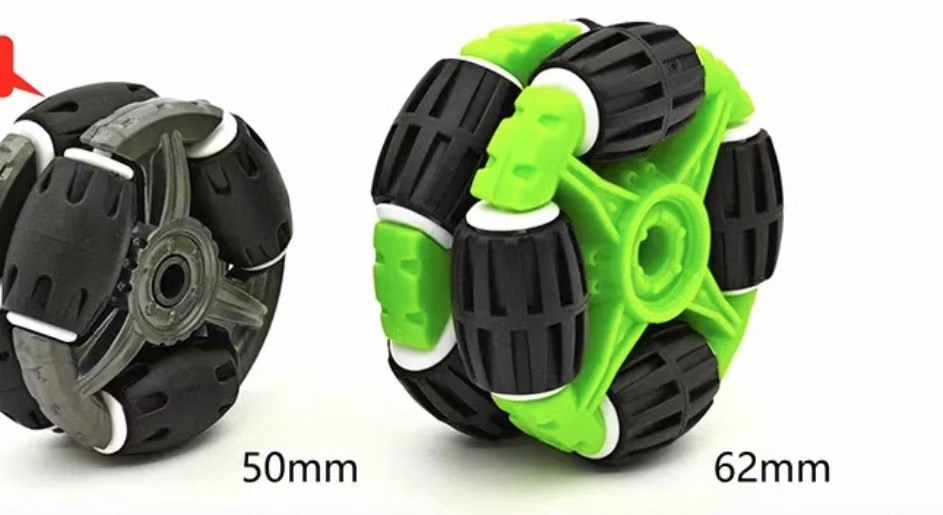
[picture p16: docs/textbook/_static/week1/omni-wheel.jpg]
Omni wheel
  <figure><figcaption>50 mm omni wheel</figcaption></figure>
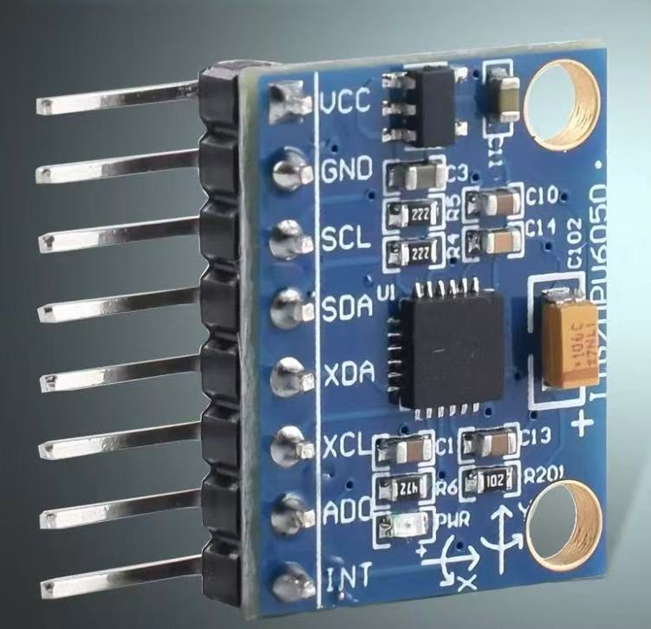
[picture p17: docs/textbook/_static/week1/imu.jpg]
MPU6050 IMU board
  <figure><figcaption>MPU6050 IMU</figcaption></figure>
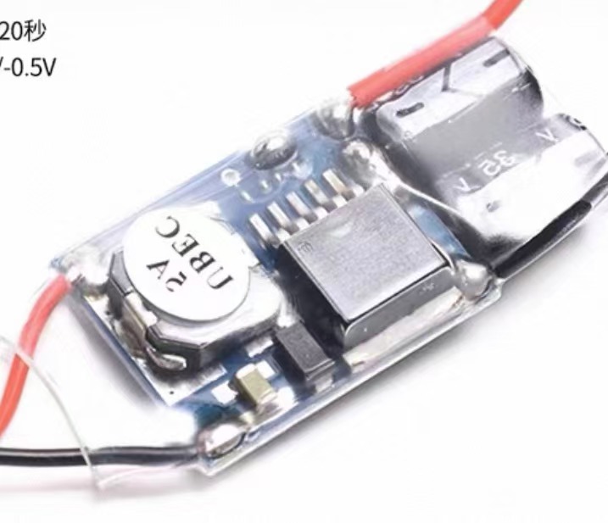
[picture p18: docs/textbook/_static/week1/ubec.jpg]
UBEC power module
  <figure><figcaption>5 V UBEC</figcaption></figure>
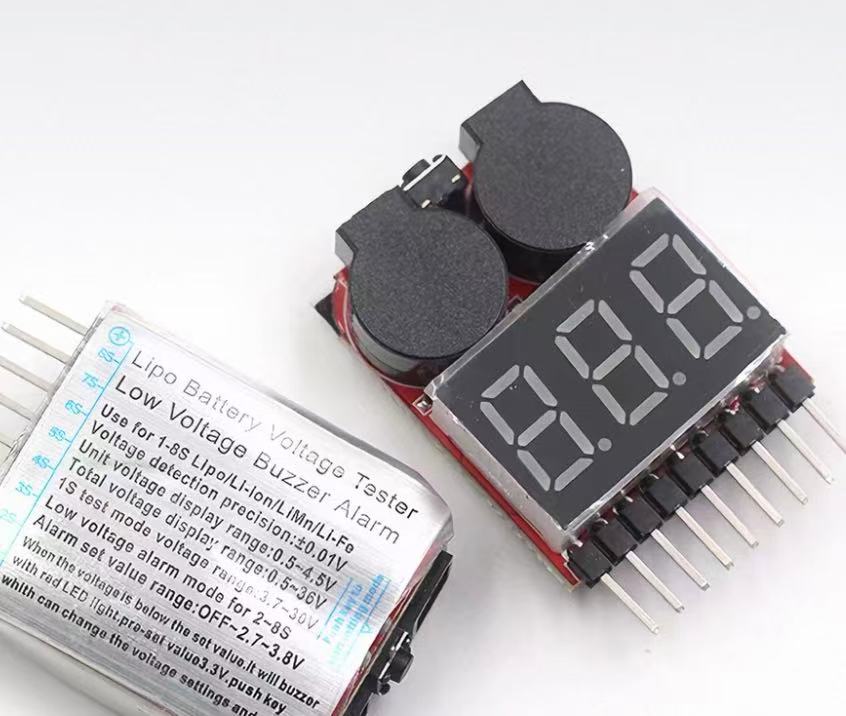
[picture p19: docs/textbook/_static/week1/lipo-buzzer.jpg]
LiPo battery alarm
  <figure><figcaption>LiPo alarm</figcaption></figure>
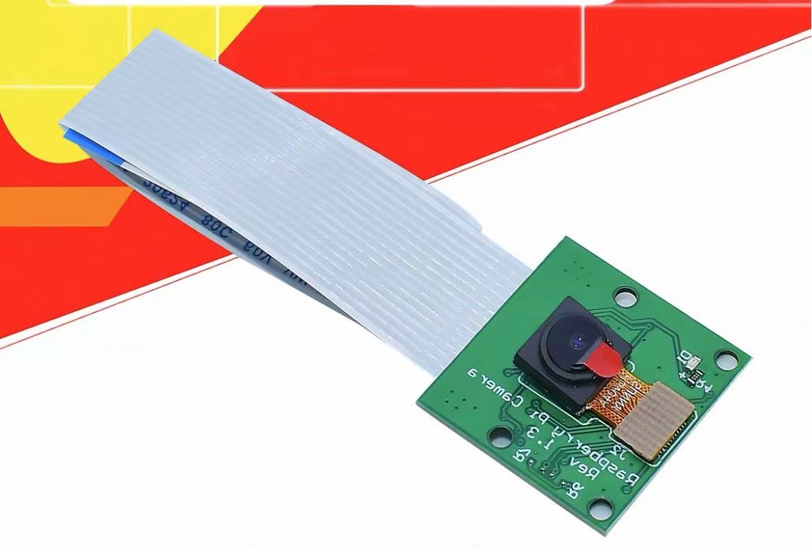
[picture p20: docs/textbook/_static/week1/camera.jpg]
Small ribbon cable camera
  <figure><figcaption>Camera</figcaption></figure>
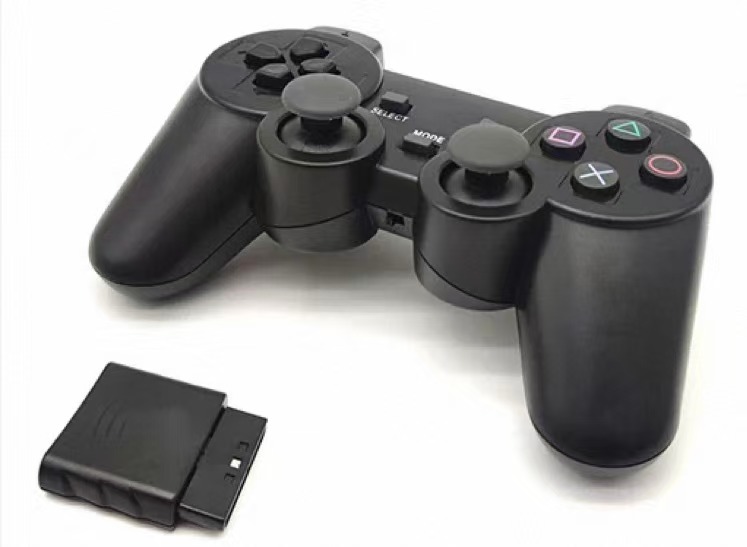
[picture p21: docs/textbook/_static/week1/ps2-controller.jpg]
Wireless PS2 style controller
  <figure><figcaption>PS2 controller</figcaption></figure>
</div>

### Battery and power

I considered a USB power bank, loose-cell battery holders, and a LiPo pack.
Battery holders used too much space, while a power bank cost more and included
features I did not need. I chose a 3S 1500 mAh 35C LiPo, recorded as 11.4 V,
because it also works with common RC connectors and power parts.

The battery rail powers the motor side of the TB6612 boards. At first, one
5 V, 5 A UBEC powered the low-voltage electronics. Later, I moved the Raspberry
Pi to its own 5 V, 5 A supply branch so that a fault in the motor-control branch
was less likely to reach the most expensive board.

Two power branches do not automatically provide galvanic isolation. They can
still share ground, and CAN or UART signals can also connect the two sides. A
real isolation plan must consider both power and communication paths.

An isolated DC-DC converter can reduce fault spread, but it cannot prevent
every short circuit. The power design must also include fuses, current limits,
clear wire colors, correct connectors, and one-branch-at-a-time testing.

### Full wiring reference

The diagram below records the complete breadboard wiring. It is dense because
it shows almost every connection in one view. Use the PDF for zooming, and use
the source files when you need to edit the circuit.

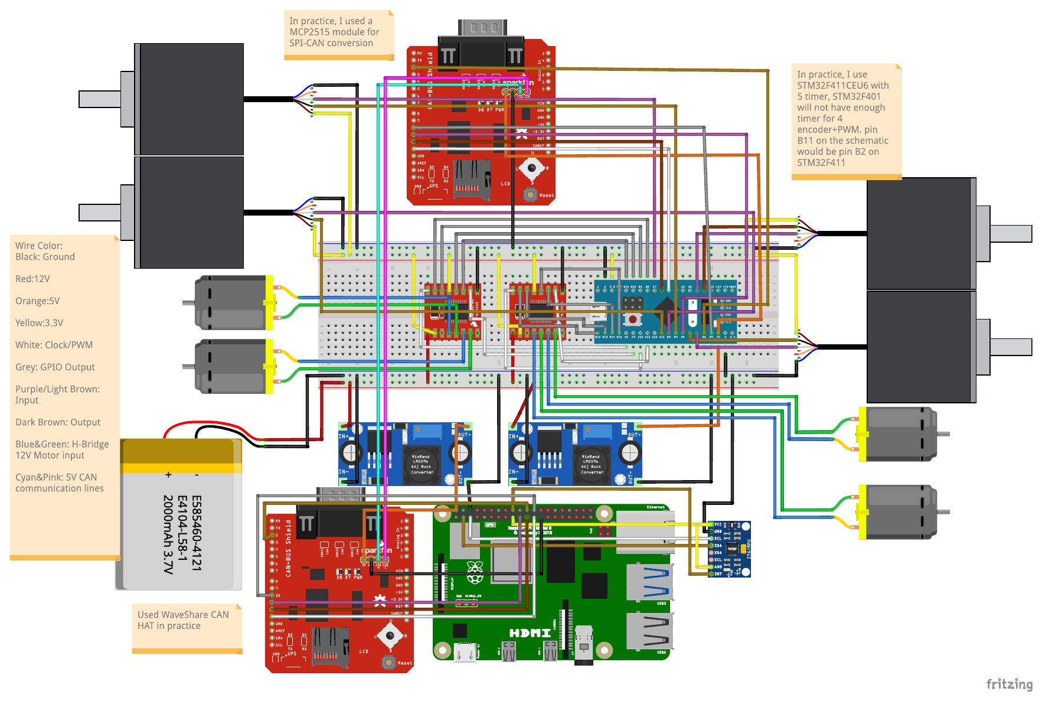
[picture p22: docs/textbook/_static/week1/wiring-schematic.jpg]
:::{figure} ../_static/week1/wiring-schematic.jpg
:alt: Full Fritzing breadboard wiring diagram for the rover
:class: chapter-wide-figure
:align: center

Breadboard wiring for the rover.
:::

<p><a href="../_static/week1/wiring-schematic.pdf">Download the full wiring PDF</a></p>

- [Open the Fritzing source](https://github.com/Tuomaaa/XDriveSLAMRover/blob/main/SCHE/schematic.fzz)
- [Open the KiCad schematic](https://github.com/Tuomaaa/XDriveSLAMRover/blob/main/SCHE/SCHE.kicad_sch)
- [Open the full SCHE folder](https://github.com/Tuomaaa/XDriveSLAMRover/tree/main/SCHE)

(power-rail-incident)=
### Two short-circuit accidents

I had two serious electrical faults during bring-up. The exact short point was
not proven in either case, so I do not present a likely cause as a confirmed
fact.

The first fault destroyed one ST-Link, one STM32, and two TB6612 boards. The
second destroyed one STM32 and one TB6612 board. The total loss was two STM32
boards, three TB6612 boards, and one ST-Link. The Raspberry Pi stayed safe
because I treated its power path separately.

After a possible short, I use this first check:

1. Remove the battery, USB cable, ST-Link, and every other power source.
2. Measure resistance or continuity from GND to the 3.3 V, 5 V, and 12 V rails.
3. Verify weak GPIO and supply pins against GND.
4. Compare the reading with a known-good board when possible.
5. Watch whether resistance rises while capacitors charge.
6. Test the ST-Link by itself. My failed unit no longer lit up.
7. Reconnect one module at a time with a current-limited bench supply.

A continuity beep is only a quick clue. It does not prove that a board is
broken, and no beep does not prove that the board is healthy. A damaged board
can still fail only when power or communication is applied.

The main lesson is to respect the 12 V rail. Turn off all power before changing
wires, keep high- and low-voltage wiring easy to separate, use fuses and current
limits, and keep spare low-cost boards during bring-up.

## Part 2 - Program the rover

Hardware and firmware are part of the same bring-up process. A motor is not
ready until software can drive it safely, and an encoder is not ready until its
count can be observed.

STM32 was a good hardware choice, but its tools took much more time than I
expected. The shortest workflow that worked for me was:

1. Set pins and peripherals in STM32CubeMX.
2. Generate the project.
3. Build it with CMake in VS Code.
4. Flash the result with STM32CubeProgrammer.
5. Use CAN and small Python tools for testing.

### How to read the repository

Do not start by reading every file from top to bottom. Follow the system from
hardware configuration to firmware and then to the Raspberry Pi.

| Order | File | What to learn from it |
| --- | --- | --- |
| 1 | [SummerSLAM.ioc](https://github.com/Tuomaaa/XDriveSLAMRover/blob/main/stm32/SummerSLAM.ioc) | Open it in CubeMX. Verify the pinout, clock tree, timers, SPI, GPIO, and code-generation settings. |
| 2 | [CMakePresets.json](https://github.com/Tuomaaa/XDriveSLAMRover/blob/main/stm32/CMakePresets.json) | Read the Debug and Release presets, build folder, generator, and toolchain file. |
| 3 | [CMakeLists.txt](https://github.com/Tuomaaa/XDriveSLAMRover/blob/main/stm32/CMakeLists.txt) | See how the firmware target includes the CubeMX-generated CMake project. |
| 4 | [main.c](https://github.com/Tuomaaa/XDriveSLAMRover/blob/main/stm32/Core/Src/main.c) | Read the motor map, encoder code, PWM code, startup, CAN receive path, and 20 ms control loop. |
| 5 | [mcp2515.c](https://github.com/Tuomaaa/XDriveSLAMRover/blob/main/stm32/Core/Src/mcp2515.c) | Read only the mode, bitrate, send, and receive functions first. Most register helpers can wait. |
| 6 | [protocol.py](https://github.com/Tuomaaa/XDriveSLAMRover/blob/main/ros2_ws/src/protocol.py) | Treat this as the message contract between C and Python. |
| 7 | [can_interface.py](https://github.com/Tuomaaa/XDriveSLAMRover/blob/main/ros2_ws/src/can_interface.py) | See the small SocketCAN wrapper used by the Pi tools. |
| 8 | [encoder_monitor.py](https://github.com/Tuomaaa/XDriveSLAMRover/blob/main/ros2_ws/src/encoder_monitor.py) | See how raw CAN encoder frames become a simple four-wheel test display. |
| 9 | [PS2.py](https://github.com/Tuomaaa/XDriveSLAMRover/blob/main/ros2_ws/src/PS2.py) and [PS2_Drive_Test.py](https://github.com/Tuomaaa/XDriveSLAMRover/blob/main/ros2_ws/src/PS2_Drive_Test.py) | Read the low-level controller driver first, then the program that maps input to CAN motor commands. |

For main.c, the fastest reading order is:

1. [MotorPosition and the motor table](https://github.com/Tuomaaa/XDriveSLAMRover/blob/main/stm32/Core/Src/main.c#L58)
2. [Encoder update logic](https://github.com/Tuomaaa/XDriveSLAMRover/blob/main/stm32/Core/Src/main.c#L155)
3. [PWM and direction logic](https://github.com/Tuomaaa/XDriveSLAMRover/blob/main/stm32/Core/Src/main.c#L185)
4. [Encoder and PWM startup](https://github.com/Tuomaaa/XDriveSLAMRover/blob/main/stm32/Core/Src/main.c#L257)
5. [CAN receive and heartbeat handling](https://github.com/Tuomaaa/XDriveSLAMRover/blob/main/stm32/Core/Src/main.c#L291)
6. [The 20 ms motor and encoder loop](https://github.com/Tuomaaa/XDriveSLAMRover/blob/main/stm32/Core/Src/main.c#L317)
7. [Encoder CAN frames](https://github.com/Tuomaaa/XDriveSLAMRover/blob/main/stm32/Core/Src/main.c#L364)

This order shows the control flow before the low-level details.

### Configure STM32CubeMX

Download
[STM32CubeMX](https://www.st.com/en/development-tools/stm32cubemx.html), then
open SummerSLAM.ioc instead of creating the configuration again by hand.

Inside CubeMX, read these views in order:

1. Pinout and Configuration: verify TIM1 PWM, TIM2-TIM5 encoder mode, SPI1,
   MCP2515 GPIO, motor direction GPIO, and SWD.
2. Clock Configuration: verify the 100 MHz system clock.
3. Project Manager: verify the project name and CMake toolchain choice.
4. Generate Code: regenerate only after you verify which project files CubeMX
   can overwrite.

The important lesson is that the .ioc file is the hardware setup. The generated
C files are an output of that setup.

### Build with CMake in VS Code

The project already contains the build files. Start with CMakePresets.json, then
read the root CMakeLists.txt, and only then open the generated
cmake/stm32cubemx/CMakeLists.txt.

From the stm32 folder, the command-line form is:

:::{code-block} console
cmake --preset Debug
cmake --build --preset Debug
:::

The same presets can be selected from the CMake tools in VS Code. I installed
the STM32 extension, but I never made every feature in that extension work
reliably. Building in VS Code and flashing with a separate ST tool was a simpler
and more stable workflow.

Embedded build errors often arrive as a long chain: compiler path, CMake
generator, Ninja, include path, generated source, and library errors can all
look related. An LLM is useful for turning the full error message into a short
test list. I recommend changing one item at a time and rebuilding after each
change, rather than accepting a large tool-generated rewrite.

### Flash with STM32CubeProgrammer

I used
[STM32CubeProgrammer](https://www.st.com/en/development-tools/stm32cubeprog.html)
instead of spending more time on the VS Code flashing tools.

Connect the ST-Link to SWDIO, SWCLK, GND, and the correct reference voltage.
Open CubeProgrammer, connect to the target, select the ELF file produced in the
Debug build folder, program it, verify it, and reset the board.

A USB-to-TTL adapter is also useful for simple debug text. Verify the current
.ioc file before connecting it, because this project later reused the original
UART pins for the ultrasonic sensors.

### Finalize Dupont wiring, then draw the PCB

I delayed the PCB because PCB design sounded much more difficult than it really
was. Online advice quickly leads to topics such as 90-degree corners, SI/PI,
return paths, crosstalk, and many other rules. I felt that I needed to
understand all of them before drawing a board.

That was the wrong priority for this rover.

Dupont wiring is already a poor electrical and mechanical system. The wires are
long, contacts can become loose, the routing is hard to read, and moving one
wire can disturb another. Even a rough but correctly connected working PCB will
usually be more stable and easier to debug than the Dupont harness I ended up
using.

The important condition is to finalize the wiring first. Use Dupont wires to
prove the pin map, power rails, motor channels, encoder channels, and
communication link. Once those connections stop changing, draw the schematic
and make the PCB. Do not wait until the end of the project.

For a low-speed rover like this one, do not let advanced SI/PI advice stop the
first board. Draw clear connections, use correct voltage and polarity, add
decoupling, choose traces that can carry the current, label connectors, and run
ERC and DRC. A right-angle trace is not the main risk here. A loose Dupont
wire or a wrong power connection is much more likely to cause trouble.

An LLM can help review the schematic and can notice a missing connection or a
wrong net name. It is less reliable at checking the full PCB layout, so use
datasheets, ERC, DRC, and your own review for that step.

My practical advice is: once the wiring works and is final, just draw the PCB.
Order it while working on kinematics, so manufacturing time runs in parallel
with software work.

### Make one motor turn

Make the first firmware test small. Lift the wheel off the floor, start one
TIM1 PWM channel, set the two direction pins, and begin with a low duty cycle.
After one channel works, repeat the same test for the other three motors.

The complete implementation is in
[motor_set_pwm()](https://github.com/Tuomaaa/XDriveSLAMRover/blob/main/stm32/Core/Src/main.c#L185).
Read that function together with the
[four PWM start calls](https://github.com/Tuomaaa/XDriveSLAMRover/blob/main/stm32/Core/Src/main.c#L264).
The first link explains direction and duty limits. The second shows which timer
channels must be running.

Testing one motor first makes power, direction, and pin errors much easier to
locate. Testing all four at once gives too many possible causes when nothing
moves.

### Read all four encoders

The STM32 timers can decode quadrature encoder signals in hardware. The startup
code enables TIM2, TIM3, TIM4, and TIM5 with TIM_CHANNEL_ALL.

Read
[encoder_update()](https://github.com/Tuomaaa/XDriveSLAMRover/blob/main/stm32/Core/Src/main.c#L155)
before reading the CAN transmit code. The function shows why TIM3 and TIM4 need
software overflow handling: they are 16-bit timers, while TIM2 and TIM5 are
32-bit.

At this stage, the goal is only to verify that every encoder count changes.
Wheel labels, sign, counts per revolution, and the X-drive scale are handled in
the Week 3 odometry chapter.

### Test CAN on the Raspberry Pi

The STM32 uses
[mcp2515.c](https://github.com/Tuomaaa/XDriveSLAMRover/blob/main/stm32/Core/Src/mcp2515.c).
Start by reading
[mode setup](https://github.com/Tuomaaa/XDriveSLAMRover/blob/main/stm32/Core/Src/mcp2515.c#L339),
[bitrate setup](https://github.com/Tuomaaa/XDriveSLAMRover/blob/main/stm32/Core/Src/mcp2515.c#L344),
and
[message send](https://github.com/Tuomaaa/XDriveSLAMRover/blob/main/stm32/Core/Src/mcp2515.c#L645).
The lower register helpers are useful only when debugging the driver itself.

On the Pi, read
[MsgId and timing constants](https://github.com/Tuomaaa/XDriveSLAMRover/blob/main/ros2_ws/src/protocol.py#L15),
then
[encode functions](https://github.com/Tuomaaa/XDriveSLAMRover/blob/main/ros2_ws/src/protocol.py#L57),
and finally
[decode()](https://github.com/Tuomaaa/XDriveSLAMRover/blob/main/ros2_ws/src/protocol.py#L72).
This file must match the CAN IDs and payload order in main.c.

The bus runs at 500 kbit/s. After the CAN HAT and SocketCAN interface are
configured, bring the interface up and watch raw frames:

:::{code-block} console
sudo ip link set can0 up type can bitrate 500000
candump can0
:::

For a clearer four-wheel display, run:

:::{code-block} console
cd ros2_ws/src
sudo python3 encoder_monitor.py
:::

Turn one wheel at a time. The raw view shows CAN IDs 0x200 and 0x201, while
encoder_monitor.py shows which motor count changed.

(can-stack-failures)=
### CAN and tool problems I found

- The MCP2515 library read the wrong register after sending a frame. The fix was
  to read the real TXBnCTRL register.
- The library did not include the can_frame type and SocketCAN-style flags used
  by this project, so I added can.h.
- CubeMX code generation can remove manual CMake source entries. Verify that
  mcp2515.c is still part of the build after regeneration.
- A Python match case used a plain name, which Python treated as a new variable
  instead of a value to compare. The decoder now uses if and elif.
- Raspberry Pi GPIO is not 5 V tolerant. The PS2 receiver uses 3.3 V logic,
  while the TJA1050 module still needs its stated 5 V supply.

### Add the PS2 controller

I did not include a hand controller in the first plan. Later, I bought a
low-cost PS2-style wireless controller so I can test the rover without
writing a full ROS command path first.

Read the controller files in two layers. In
[PS2.py](https://github.com/Tuomaaa/XDriveSLAMRover/blob/main/ros2_ws/src/PS2.py),
start with
[PS2Controller](https://github.com/Tuomaaa/XDriveSLAMRover/blob/main/ros2_ws/src/PS2.py#L121),
then read
[the byte transfer](https://github.com/Tuomaaa/XDriveSLAMRover/blob/main/ros2_ws/src/PS2.py#L141)
and
[the packet read](https://github.com/Tuomaaa/XDriveSLAMRover/blob/main/ros2_ws/src/PS2.py#L165).
The lower _RawGPIO class is only the GPIO access layer.

Next, open
[PS2_Drive_Test.py](https://github.com/Tuomaaa/XDriveSLAMRover/blob/main/ros2_ws/src/PS2_Drive_Test.py).
Read the
[heartbeat thread](https://github.com/Tuomaaa/XDriveSLAMRover/blob/main/ros2_ws/src/PS2_Drive_Test.py#L35)
before the
[main drive loop](https://github.com/Tuomaaa/XDriveSLAMRover/blob/main/ros2_ws/src/PS2_Drive_Test.py#L64).
The heartbeat must keep running even when a controller read takes time.

Run the drive test with:

:::{code-block} console
cd ros2_ws/src
sudo python3 PS2_Drive_Test.py
:::

Lift the rover before the first test. Verify forward, reverse, left, and right,
keep a fast way to remove power, and verify the heartbeat stop before driving
on the floor.

The low-level controller driver took more time than it deserved. This protocol
is not the main research topic, so using an existing library or an LLM-assisted
driver is reasonable. The real hardware checks still matter: verify the logic
voltage, clock timing, button map, disconnect behavior, and stop path.

### Drive test

The video shows the rover moving during bring-up.

<video class="chapter-video" controls preload="metadata">
  <source src="../_static/week1/drive-test.mp4" type="video/mp4">
  Your browser does not support this video.
</video>

The video proves that the rover can move, but it is not a full safety or
performance test. It does not measure motor speed, current, controller
disconnect behavior, or heartbeat timing.

## What worked at the end

One motor worked first, followed by all four motors. The encoders produced
counts, and the STM32 sent encoder frames to the Raspberry Pi over the real CAN
link. The rover also moved during the drive test.

These results verify the basic frame, power path, motor drivers, PWM, encoder
capture, CAN transport, and manual command path. They do not claim that
closed-loop speed control, calibrated odometry, full controller safety,
localization, or SLAM was complete at this stage.

## Main lessons

1. Finalize the physical BOM before placing every mounting hole.
2. Count timers, channels, and pin conflicts before choosing the MCU.
3. Use UART unless CAN is part of the learning goal.
4. Draw and review the power path before connecting the LiPo.
5. Add fuses, current limits, and connectors that cannot be reversed.
6. Keep 12 V, 5 V, and 3.3 V wiring easy to identify.
7. Test one power branch and one motor channel at a time.
8. Keep spare STM32, TB6612, and ST-Link boards during bring-up.
9. Once the Dupont wiring works and is final, draw the PCB instead of waiting.
10. Leave mechanical room for later sensors and wiring.

## Source index

- [STM32 CubeMX configuration](https://github.com/Tuomaaa/XDriveSLAMRover/blob/main/stm32/SummerSLAM.ioc)
- [STM32 main firmware](https://github.com/Tuomaaa/XDriveSLAMRover/blob/main/stm32/Core/Src/main.c)
- [MCP2515 driver](https://github.com/Tuomaaa/XDriveSLAMRover/blob/main/stm32/Core/Src/mcp2515.c)
- [CAN message protocol](https://github.com/Tuomaaa/XDriveSLAMRover/blob/main/ros2_ws/src/protocol.py)
- [SocketCAN wrapper](https://github.com/Tuomaaa/XDriveSLAMRover/blob/main/ros2_ws/src/can_interface.py)
- [Encoder monitor](https://github.com/Tuomaaa/XDriveSLAMRover/blob/main/ros2_ws/src/encoder_monitor.py)
- [PS2 low-level driver](https://github.com/Tuomaaa/XDriveSLAMRover/blob/main/ros2_ws/src/PS2.py)
- [PS2 drive test](https://github.com/Tuomaaa/XDriveSLAMRover/blob/main/ros2_ws/src/PS2_Drive_Test.py)
- [Fritzing wiring source](https://github.com/Tuomaaa/XDriveSLAMRover/blob/main/SCHE/schematic.fzz)
- [KiCad schematic](https://github.com/Tuomaaa/XDriveSLAMRover/blob/main/SCHE/SCHE.kicad_sch)
- [Project state and decision log](https://github.com/Tuomaaa/XDriveSLAMRover/blob/main/PROJECT_STATE.md)

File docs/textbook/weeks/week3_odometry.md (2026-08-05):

# Week 3 - X-Drive Kinematics and Encoder Odometry

:::{admonition} Chapter status: implemented, with validation still in progress
:class: status status-progress

The kinematics, encoder calibration, and pose estimator are implemented. I
verified the wheel map, encoder signs, CPR, frame direction, and a left-strafe
smoke test. Longer ground-truth runs, drift measurements, and a complete ROS
and TF test on the Raspberry Pi are not complete, so this chapter does not
claim that the final odometry accuracy is known.
:::

:::{admonition} File guide
:class: tip

**Core algorithm — read this first**

- [`odometry.py`](https://github.com/Tuomaaa/XDriveSLAMRover/blob/main/ros2_ws/src/odometry.py) — forward kinematics, `MOTOR_MAP`, `ENCODER_SIGN`, CPR, midpoint pose integration

**Recommended**

- [`main.c`](https://github.com/Tuomaaa/XDriveSLAMRover/blob/main/stm32/Core/Src/main.c) — motor order (`MotorPosition`), encoder CAN frames (0x200/0x201)
- [`encoder_monitor.py`](https://github.com/Tuomaaa/XDriveSLAMRover/blob/main/ros2_ws/src/encoder_monitor.py) — channel mapping procedure (turn one wheel, observe which column changes)
- [`PS2_Drive_Test.py`](https://github.com/Tuomaaa/XDriveSLAMRover/blob/main/ros2_ws/src/PS2_Drive_Test.py) — inverse kinematics convention

**Infrastructure — safe to skip**

- `protocol.py` — CAN decoder (covered in Weeks 1-2)
- `can_bridge_node.py` — CAN-to-ROS bridge and TF broadcast
:::

## From a moving rover to a motion estimate

Weeks 1-2 ended with a rover that can move and send encoder counts. Week 3
asks a different question: what do those four counts say about the motion of
the whole rover?

The output I want is a two-dimensional pose:

$$
\mathbf{x} =
\begin{bmatrix}
x & y & \theta
\end{bmatrix}^{T}.
$$

Encoder odometry is a form of dead reckoning. Each new wheel motion is added
to the previous pose. This makes the estimate simple and useful, but it also
means that wheel slip, scale errors, and heading errors accumulate instead of
disappearing.

The conversion path is:

1. Receive four cumulative encoder counts.
2. Subtract the previous counts.
3. Correct the encoder wiring map and count directions.
4. Convert tick changes into wheel velocities.
5. Use X-drive forward kinematics to find body velocity.
6. Rotate that motion into the `odom` frame.
7. Integrate it into the next pose.

The equations were not the most difficult part. Most of my debugging time went
into deciding which physical wheel each number represented, which direction
was positive, and which coordinate convention the controller was using.

## How to read the repository

Follow the data from the STM32 to the final ROS message. Reading the files in
this order makes the boundaries between wiring, protocol, mathematics, and ROS
clear.

| Order | File | What to read |
| ---: | --- | --- |
| 1 | [main.c motor order](https://github.com/Tuomaaa/XDriveSLAMRover/blob/main/stm32/Core/Src/main.c#L58) | Start with `MotorPosition`, then read the two encoder CAN frames. This is the motor-side order. |
| 2 | [protocol.py decoder](https://github.com/Tuomaaa/XDriveSLAMRover/blob/main/ros2_ws/src/protocol.py#L72) | See how CAN `0x200` and `0x201` become two pairs of signed 32-bit cumulative counts. |
| 3 | [encoder_monitor.py main loop](https://github.com/Tuomaaa/XDriveSLAMRover/blob/main/ros2_ws/src/encoder_monitor.py#L33) | Read the baseline and delta logic. During mapping, turn one wheel at a time and treat the four columns as observed channels rather than trusting a wheel name in advance. |
| 4 | [odometry.py configuration](https://github.com/Tuomaaa/XDriveSLAMRover/blob/main/ros2_ws/src/odometry.py#L27) | Read the geometry, translation scale, CPR, `MOTOR_MAP`, and `ENCODER_SIGN` before reading the equations. |
| 5 | [OdometryEstimator.update()](https://github.com/Tuomaaa/XDriveSLAMRover/blob/main/ros2_ws/src/odometry.py#L114) | Follow one update from tick subtraction through kinematics and midpoint integration. |
| 6 | [can_bridge_node.py encoder path](https://github.com/Tuomaaa/XDriveSLAMRover/blob/main/ros2_ws/src/can_bridge_node.py#L106) | See how the bridge collects both frames, calls the estimator, publishes `odom`, and broadcasts TF. |
| 7 | [PS2_Drive_Test.py inverse kinematics](https://github.com/Tuomaaa/XDriveSLAMRover/blob/main/ros2_ws/src/PS2_Drive_Test.py#L120) | Read this last. It explains the command convention that the forward kinematics must invert. |

Inside `odometry.py`, the fastest reading order is:

1. [Physical and calibration constants](https://github.com/Tuomaaa/XDriveSLAMRover/blob/main/ros2_ws/src/odometry.py#L27)
2. [Encoder harness map](https://github.com/Tuomaaa/XDriveSLAMRover/blob/main/ros2_ws/src/odometry.py#L46)
3. [Encoder sign correction](https://github.com/Tuomaaa/XDriveSLAMRover/blob/main/ros2_ws/src/odometry.py#L69)
4. [Tick-to-wheel conversion](https://github.com/Tuomaaa/XDriveSLAMRover/blob/main/ros2_ws/src/odometry.py#L90)
5. [Forward kinematics](https://github.com/Tuomaaa/XDriveSLAMRover/blob/main/ros2_ws/src/odometry.py#L160)
6. [Midpoint pose integration](https://github.com/Tuomaaa/XDriveSLAMRover/blob/main/ros2_ws/src/odometry.py#L164)
7. [Standalone smoke test](https://github.com/Tuomaaa/XDriveSLAMRover/blob/main/ros2_ws/src/odometry.py#L185)

This order keeps a wiring correction from looking like part of the kinematic
equation.

## Define one coordinate frame first

I use the ROS REP-103 convention:

- $+x$ points forward.
- $+y$ points left.
- $+z$ points upward.
- Positive $\theta$ is counter-clockwise when viewed from above.

The wheel names are `fl`, `fr`, `rl`, and `rr`. They mean front-left,
front-right, rear-left, and rear-right.

The measured geometry used by the estimator is:

$$
r = 0.025\ \mathrm{m},
\qquad
R = 0.115\ \mathrm{m},
$$

where $r$ is wheel radius and $R$ is the distance from the rover center to a
wheel contact point.

The corresponding configuration is kept together near the top of
[`odometry.py`](https://github.com/Tuomaaa/XDriveSLAMRover/blob/main/ros2_ws/src/odometry.py#L27):

```python
WHEEL_RADIUS_M = 0.025
CENTER_TO_WHEEL_M = 0.115
TRANSLATION_SCALE = math.sqrt(2)
ENCODER_CPR = 2779
```

Keeping these values outside the estimator makes it clear which numbers come
from the physical rover or calibration. A change to the chassis must update
this block.

The two rear channels show why position names and numeric indexes must be kept
separate:

| Physical wheel | Motor command index | Encoder channel index |
| --- | ---: | ---: |
| Front-left | 0 | 0 |
| Front-right | 1 | 1 |
| Rear-left | 2 | 3 |
| Rear-right | 3 | 2 |

The motor indexes follow the intended drive wiring. The encoder indexes follow
the harness that was actually built. Both tables are true at the same time.

## Why the STM32 sends cumulative counts

The STM32 extends the encoder timers into cumulative 32-bit counts and sends
them in two CAN frames:

- `0x200`: channels 0 and 1
- `0x201`: channels 2 and 3

The frame construction is visible in
[main.c](https://github.com/Tuomaaa/XDriveSLAMRover/blob/main/stm32/Core/Src/main.c#L364).
The Python decoder for the same payload is in
[protocol.py](https://github.com/Tuomaaa/XDriveSLAMRover/blob/main/ros2_ws/src/protocol.py#L72).
Read these two files together whenever the CAN layout changes.

For wheel $i$, the estimator calculates:

$$
\Delta N_i = N_{i,k} - N_{i,k-1}.
$$

Cumulative counts are useful because one lost CAN frame does not permanently
lose its motion. The next received total still includes the missing interval.
With per-frame deltas, that motion is gone.

The first sample cannot produce a delta, so `update()` stores it as a baseline
and returns no pose result. It also rejects duplicate or out-of-order
timestamps instead of dividing by zero or integrating backward.

## Convert ticks into wheel velocity

Let $C$ be encoder counts per output-shaft revolution. For a measured time gap
$\Delta t$, the wheel-surface velocity is:

$$
u_i =
\frac{2\pi r\Delta N_i}{C\Delta t}.
$$

The implementation is
[ticks_to_wheel_velocity()](https://github.com/Tuomaaa/XDriveSLAMRover/blob/main/ros2_ws/src/odometry.py#L90).

```python
def ticks_to_wheel_velocity(delta_ticks: int, dt: float) -> float:
    if dt <= 0:
        return 0.0
    rev_per_sec = (delta_ticks / dt) / ENCODER_CPR
    return rev_per_sec * 2.0 * math.pi * WHEEL_RADIUS_M
```

Read the expression from left to right: ticks per second become output-shaft
revolutions per second, then circumference converts revolutions into meters.
The `dt <= 0` guard prevents a duplicate or reversed timestamp from producing
an invalid velocity.

The STM32 sends encoder frames near 50 Hz, but Linux and CAN timing do not make
every gap exactly 20 ms. The estimator therefore uses the actual CAN receive
timestamps:

$$
\Delta t = t_k - t_{k-1}.
$$

This prevents scheduling jitter from being treated as a change in wheel
speed. The bridge waits until frame `0x201` completes the four-channel set,
then calls the estimator with that frame's timestamp. Read that handoff in
[can_bridge_node.py](https://github.com/Tuomaaa/XDriveSLAMRover/blob/main/ros2_ws/src/can_bridge_node.py#L120).

```python
base = result.motor_id * 2
self._ticks[base] = result.motor_a_ticks
self._ticks[base + 1] = result.motor_b_ticks

if result.motor_id == 1 and len(self._ticks) == 4:
    self._on_encoder_complete(msg.timestamp)
```

`motor_id` is `0` for CAN frame `0x200` and `1` for `0x201`. Multiplying it by
two places each pair into indexes `0,1` or `2,3`. The estimator runs only when
the second frame arrives and all four entries exist.

This pairing is intentionally simple. There is no sequence number, so a rare
lost or reordered half-pair can still combine counts from different instants.
Cumulative counts reduce the damage, but they do not make the pairing perfect.
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

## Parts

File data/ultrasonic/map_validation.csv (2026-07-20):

Position | Label | Offset_X_mm | Offset_Y_mm | Sample | Right_mm | Back_mm
P1 | Center | 0 | 0 | 1 | 482.5 | 490.6
P1 | Center | 0 | 0 | 2 | 492.5 | 493.7
P1 | Center | 0 | 0 | 3 | 486.4 | 487.3
P1 | Center | 0 | 0 | 4 | 487.6 | 481.8
P1 | Center | 0 | 0 | 5 | 501.6 | 486.9
P1 | Center | 0 | 0 | 6 | 491.2 | 495.1
P1 | Center | 0 | 0 | 7 | 491.6 | 485.4
P1 | Center | 0 | 0 | 8 | 487.0 | 489.3
P1 | Center | 0 | 0 | 9 | 490.7 | 496.0
P1 | Center | 0 | 0 | 10 | 492.4 | 483.1
P1 | Center | 0 | 0 | 11 | 482.8 | 491.2
P1 | Center | 0 | 0 | 12 | 501.8 | 502.0
P1 | Center | 0 | 0 | 13 | 499.9 | 493.7
P1 | Center | 0 | 0 | 14 | 489.8 | 491.7
P1 | Center | 0 | 0 | 15 | 493.0 | 503.0
P1 | Center | 0 | 0 | 16 | 484.2 | 487.8
P1 | Center | 0 | 0 | 17 | 488.7 | 493.5
P1 | Center | 0 | 0 | 18 | 487.7 | 496.6
P1 | Center | 0 | 0 | 19 | 490.7 | 498.1
P1 | Center | 0 | 0 | 20 | 492.5 | 492.6
P1 | Center | 0 | 0 | 21 | 489.9 | 501.4
P1 | Center | 0 | 0 | 22 | 498.6 | 497.0
P1 | Center | 0 | 0 | 23 | 495.5 | 494.0
P1 | Center | 0 | 0 | 24 | 490.6 | 489.8
P1 | Center | 0 | 0 | 25 | 490.0 | 492.0
P1 | Center | 0 | 0 | 26 | 493.0 | 483.7
P1 | Center | 0 | 0 | 27 | 493.4 | 498.8
P1 | Center | 0 | 0 | 28 | 499.9 | 481.2
P1 | Center | 0 | 0 | 29 | 490.4 | 498.9
P1 | Center | 0 | 0 | 30 | 496.8 | 493.3
P1 | Center | 0 | 0 | 31 | 505.7 | 495.8
P1 | Center | 0 | 0 | 32 | 498.9 | 496.0
P1 | Center | 0 | 0 | 33 | 491.0 | 491.8
P1 | Center | 0 | 0 | 34 | 505.7 | 490.3
P1 | Center | 0 | 0 | 35 | 490.5 | 500.6
P1 | Center | 0 | 0 | 36 | 493.9 | 489.3
P1 | Center | 0 | 0 | 37 | 492.4 | 492.4
P1 | Center | 0 | 0 | 38 | 496.3 | 492.3
P1 | Center | 0 | 0 | 39 | 494.1 | 496.0
P1 | Center | 0 | 0 | 40 | 488.3 | 493.4
P1 | Center | 0 | 0 | 41 | 495.2 | 498.7
P1 | Center | 0 | 0 | 42 | 500.5 | 490.5
P1 | Center | 0 | 0 | 43 | 499.0 | 494.6
P1 | Center | 0 | 0 | 44 | 500.0 | 505.6
P1 | Center | 0 | 0 | 45 | 493.9 | 499.5
P1 | Center | 0 | 0 | 46 | 490.9 | 488.8
P1 | Center | 0 | 0 | 47 | 479.0 | 483.8
P1 | Center | 0 | 0 | 48 | 492.2 | 487.9
P1 | Center | 0 | 0 | 49 | 484.7 | 493.4
P1 | Center | 0 | 0 | 50 | 488.4 | 495.6
P1 | Center | 0 | 0 | 51 | 492.2 | 491.9
P1 | Center | 0 | 0 | 52 | 491.9 | 485.8
P1 | Center | 0 | 0 | 53 | 492.2 | 488.1
P1 | Center | 0 | 0 | 54 | 497.1 | 496.0
P1 | Center | 0 | 0 | 55 | 492.4 | 492.4
P1 | Center | 0 | 0 | 56 | 488.6 | 483.6
P1 | Center | 0 | 0 | 57 | 488.6 | 489.5
P1 | Center | 0 | 0 | 58 | 498.5 | 491.4
P1 | Center | 0 | 0 | 59 | 484.6 | 497.1
P1 | Center | 0 | 0 | 60 | 492.8 | 484.9
P1 | Center | 0 | 0 | 61 | 498.0 | 504.5
P1 | Center | 0 | 0 | 62 | 494.0 | 492.3
P1 | Center | 0 | 0 | 63 | 482.7 | 493.8
P1 | Center | 0 | 0 | 64 | 491.9 | 496.8
P1 | Center | 0 | 0 | 65 | 496.3 | 493.3
P1 | Center | 0 | 0 | 66 | 492.7 | 489.0
P1 | Center | 0 | 0 | 67 | 490.1 | 493.5
P1 | Center | 0 | 0 | 68 | 493.8 | 490.3
P1 | Center | 0 | 0 | 69 | 492.5 | 492.8
P1 | Center | 0 | 0 | 70 | 480.8 | 498.6
P1 | Center | 0 | 0 | 71 | 506.3 | 500.3
P1 | Center | 0 | 0 | 72 | 491.0 | 489.2
P1 | Center | 0 | 0 | 73 | 495.4 | 491.5
P1 | Center | 0 | 0 | 74 | 495.4 | 492.7
P1 | Center | 0 | 0 | 75 | 498.6 | 498.5
P1 | Center | 0 | 0 | 76 | 495.1 | 498.4
P1 | Center | 0 | 0 | 77 | 497.0 | 493.2
P1 | Center | 0 | 0 | 78 | 494.5 | 502.9
P1 | Center | 0 | 0 | 79 | 497.0 | 493.6
P1 | Center | 0 | 0 | 80 | 496.9 | 486.9
P1 | Center | 0 | 0 | 81 | 495.5 | 502.7
P1 | Center | 0 | 0 | 82 | 497.0 | 493.0
P1 | Center | 0 | 0 | 83 | 505.8 | 488.1
P1 | Center | 0 | 0 | 84 | 485.2 | 490.5
P1 | Center | 0 | 0 | 85 | 489.0 | 496.9
P1 | Center | 0 | 0 | 86 | 494.0 | 490.3
P1 | Center | 0 | 0 | 87 | 488.7 | 492.2
P1 | Center | 0 | 0 | 88 | 499.4 | 483.6
P1 | Center | 0 | 0 | 89 | 492.3 | 496.3
P1 | Center | 0 | 0 | 90 | 488.2 | 495.0
P1 | Center | 0 | 0 | 91 | 488.2 | 486.9
P1 | Center | 0 | 0 | 92 | 493.3 | 493.3
P1 | Center | 0 | 0 | 93 | 488.1 | 488.6
P1 | Center | 0 | 0 | 94 | 486.2 | 496.3
P1 | Center | 0 | 0 | 95 | 498.6 | 490.7
P1 | Center | 0 | 0 | 96 | 488.0 | 481.0
P1 | Center | 0 | 0 | 97 | 495.3 | 500.1
P1 | Center | 0 | 0 | 98 | 487.4 | 486.7
P1 | Center | 0 | 0 | 99 | 495.8 | 487.0
P1 | Center | 0 | 0 | 100 | 491.3 | 493.3
P2 | +80mm_Right | 80 | 0 | 1 | 405.2 | 485.2
P2 | +80mm_Right | 80 | 0 | 2 | 400.2 | 478.4
P2 | +80mm_Right | 80 | 0 | 3 | 416.1 | 494.8
P2 | +80mm_Right | 80 | 0 | 4 | 408.4 | 496.9
P2 | +80mm_Right | 80 | 0 | 5 | 406.4 | 496.0
P2 | +80mm_Right | 80 | 0 | 6 | 415.6 | 491.3
P2 | +80mm_Right | 80 | 0 | 7 | 412.3 | 497.5
P2 | +80mm_Right | 80 | 0 | 8 | 418.4 | 496.2
P2 | +80mm_Right | 80 | 0 | 9 | 409.2 | 497.0
P2 | +80mm_Right | 80 | 0 | 10 | 414.8 | 493.4
P2 | +80mm_Right | 80 | 0 | 11 | 418.8 | 488.3
P2 | +80mm_Right | 80 | 0 | 12 | 409.3 | 501.9
P2 | +80mm_Right | 80 | 0 | 13 | 409.1 | 495.2
P2 | +80mm_Right | 80 | 0 | 14 | 413.8 | 487.5
P2 | +80mm_Right | 80 | 0 | 15 | 414.7 | 495.5
P2 | +80mm_Right | 80 | 0 | 16 | 400.0 | 489.3
P2 | +80mm_Right | 80 | 0 | 17 | 412.4 | 491.1
P2 | +80mm_Right | 80 | 0 | 18 | 418.6 | 492.7
P2 | +80mm_Right | 80 | 0 | 19 | 414.2 | 496.4
P2 | +80mm_Right | 80 | 0 | 20 | 410.7 | 492.5
P2 | +80mm_Right | 80 | 0 | 21 | 401.5 | 504.3
P2 | +80mm_Right | 80 | 0 | 22 | 409.0 | 483.8
P2 | +80mm_Right | 80 | 0 | 23 | 420.5 | 499.6
P2 | +80mm_Right | 80 | 0 | 24 | 399.9 | 494.0
P2 | +80mm_Right | 80 | 0 | 25 | 415.7 | 492.3
P2 | +80mm_Right | 80 | 0 | 26 | 405.2 | 488.2
P2 | +80mm_Right | 80 | 0 | 27 | 411.7 | 496.0
P2 | +80mm_Right | 80 | 0 | 28 | 415.4 | 496.7
P2 | +80mm_Right | 80 | 0 | 29 | 410.6 | 490.0
P2 | +80mm_Right | 80 | 0 | 30 | 413.9 | 493.8
P2 | +80mm_Right | 80 | 0 | 31 | 416.6 | 489.9
P2 | +80mm_Right | 80 | 0 | 32 | 403.2 | 499.2
P2 | +80mm_Right | 80 | 0 | 33 | 411.6 | 489.2
P2 | +80mm_Right | 80 | 0 | 34 | 418.7 | 492.1
P2 | +80mm_Right | 80 | 0 | 35 | 414.6 | 495.7
P2 | +80mm_Right | 80 | 0 | 36 | 411.3 | 481.0
P2 | +80mm_Right | 80 | 0 | 37 | 410.1 | 497.2
P2 | +80mm_Right | 80 | 0 | 38 | 428.2 | 495.8
P2 | +80mm_Right | 80 | 0 | 39 | 409.2 | 498.6
P2 | +80mm_Right | 80 | 0 | 40 | 420.1 | 490.5
P2 | +80mm_Right | 80 | 0 | 41 | 414.6 | 505.0
P2 | +80mm_Right | 80 | 0 | 42 | 411.7 | 482.5
P2 | +80mm_Right | 80 | 0 | 43 | 417.9 | 489.5
P2 | +80mm_Right | 80 | 0 | 44 | 419.9 | 496.7
P2 | +80mm_Right | 80 | 0 | 45 | 420.2 | 492.0
P2 | +80mm_Right | 80 | 0 | 46 | 410.9 | 498.4
P2 | +80mm_Right | 80 | 0 | 47 | 404.6 | 495.8
P2 | +80mm_Right | 80 | 0 | 48 | 408.0 | 497.1
P2 | +80mm_Right | 80 | 0 | 49 | 414.5 | 480.3
P2 | +80mm_Right | 80 | 0 | 50 | 410.3 | 497.2
P2 | +80mm_Right | 80 | 0 | 51 | 402.9 | 486.9
P2 | +80mm_Right | 80 | 0 | 52 | 412.9 | 492.0
P2 | +80mm_Right | 80 | 0 | 53 | 421.1 | 487.4
P2 | +80mm_Right | 80 | 0 | 54 | 413.7 | 499.5
P2 | +80mm_Right | 80 | 0 | 55 | 413.9 | 487.2
P2 | +80mm_Right | 80 | 0 | 56 | 412.3 | 483.5
P2 | +80mm_Right | 80 | 0 | 57 | 423.5 | 497.5
P2 | +80mm_Right | 80 | 0 | 58 | 413.2 | 499.1
P2 | +80mm_Right | 80 | 0 | 59 | 410.8 | 497.5
P2 | +80mm_Right | 80 | 0 | 60 | 410.5 | 499.9
P2 | +80mm_Right | 80 | 0 | 61 | 412.2 | 489.9
P2 | +80mm_Right | 80 | 0 | 62 | 417.0 | 498.1
P2 | +80mm_Right | 80 | 0 | 63 | 413.4 | 488.8
P2 | +80mm_Right | 80 | 0 | 64 | 408.5 | 507.2
P2 | +80mm_Right | 80 | 0 | 65 | 417.2 | 489.3
P2 | +80mm_Right | 80 | 0 | 66 | 420.4 | 506.2
P2 | +80mm_Right | 80 | 0 | 67 | 410.1 | 494.3
P2 | +80mm_Right | 80 | 0 | 68 | 422.8 | 498.2
P2 | +80mm_Right | 80 | 0 | 69 | 408.5 | 490.8
P2 | +80mm_Right | 80 | 0 | 70 | 405.6 | 494.1
P2 | +80mm_Right | 80 | 0 | 71 | 426.2 | 502.1
P2 | +80mm_Right | 80 | 0 | 72 | 415.4 | 488.3
P2 | +80mm_Right | 80 | 0 | 73 | 415.5 | 503.1
P2 | +80mm_Right | 80 | 0 | 74 | 410.8 | 491.3
P2 | +80mm_Right | 80 | 0 | 75 | 400.8 | 495.9
P2 | +80mm_Right | 80 | 0 | 76 | 406.3 | 490.8
P2 | +80mm_Right | 80 | 0 | 77 | 424.1 | 493.3
P2 | +80mm_Right | 80 | 0 | 78 | 413.9 | 491.4
P2 | +80mm_Right | 80 | 0 | 79 | 421.9 | 503.7
P2 | +80mm_Right | 80 | 0 | 80 | 411.1 | 490.0
P2 | +80mm_Right | 80 | 0 | 81 | 412.4 | 494.4
P2 | +80mm_Right | 80 | 0 | 82 | 409.4 | 495.5
P2 | +80mm_Right | 80 | 0 | 83 | 406.5 | 491.7
P2 | +80mm_Right | 80 | 0 | 84 | 416.7 | 491.9
P2 | +80mm_Right | 80 | 0 | 85 | 410.7 | 492.3
P2 | +80mm_Right | 80 | 0 | 86 | 407.6 | 488.0
P2 | +80mm_Right | 80 | 0 | 87 | 412.5 | 494.0
P2 | +80mm_Right | 80 | 0 | 88 | 413.3 | 497.5
P2 | +80mm_Right | 80 | 0 | 89 | 407.8 | 483.8
P2 | +80mm_Right | 80 | 0 | 90 | 403.6 | 477.7
P2 | +80mm_Right | 80 | 0 | 91 | 416.5 | 492.5
P2 | +80mm_Right | 80 | 0 | 92 | 407.5 | 490.7
P2 | +80mm_Right | 80 | 0 | 93 | 415.6 | 487.8
P2 | +80mm_Right | 80 | 0 | 94 | 418.2 | 485.4
P2 | +80mm_Right | 80 | 0 | 95 | 409.0 | 493.0
P2 | +80mm_Right | 80 | 0 | 96 | 419.6 | 493.0
P2 | +80mm_Right | 80 | 0 | 97 | 413.4 | 490.9
P2 | +80mm_Right | 80 | 0 | 98 | 415.7 | 498.5
P2 | +80mm_Right | 80 | 0 | 99 | 402.2 | 490.0
P2 | +80mm_Right | 80 | 0 | 100 | 411.1 | 492.6
P3 | +100mm_Back | 0 | 100 | 1 | 492.8 | 404.6
P3 | +100mm_Back | 0 | 100 | 2 | 499.5 | 393.4
P3 | +100mm_Back | 0 | 100 | 3 | 487.7 | 389.3
P3 | +100mm_Back | 0 | 100 | 4 | 485.6 | 386.3
P3 | +100mm_Back | 0 | 100 | 5 | 494.3 | 392.4
P3 | +100mm_Back | 0 | 100 | 6 | 492.9 | 385.0
P3 | +100mm_Back | 0 | 100 | 7 | 492.3 | 392.8
P3 | +100mm_Back | 0 | 100 | 8 | 496.2 | 390.3
P3 | +100mm_Back | 0 | 100 | 9 | 492.6 | 391.7
P3 | +100mm_Back | 0 | 100 | 10 | 498.3 | 386.7
P3 | +100mm_Back | 0 | 100 | 11 | 489.1 | 392.6
P3 | +100mm_Back | 0 | 100 | 12 | 485.2 | 395.9
P3 | +100mm_Back | 0 | 100 | 13 | 492.6 | 388.0
P3 | +100mm_Back | 0 | 100 | 14 | 497.1 | 396.1
P3 | +100mm_Back | 0 | 100 | 15 | 498.0 | 382.8
P3 | +100mm_Back | 0 | 100 | 16 | 493.4 | 398.1
P3 | +100mm_Back | 0 | 100 | 17 | 490.0 | 396.3
P3 | +100mm_Back | 0 | 100 | 18 | 491.1 | 384.6
P3 | +100mm_Back | 0 | 100 | 19 | 490.5 | 399.2
P3 | +100mm_Back | 0 | 100 | 20 | 492.8 | 399.9
P3 | +100mm_Back | 0 | 100 | 21 | 486.4 | 407.7
P3 | +100mm_Back | 0 | 100 | 22 | 492.1 | 391.6
P3 | +100mm_Back | 0 | 100 | 23 | 490.4 | 380.8
P3 | +100mm_Back | 0 | 100 | 24 | 494.3 | 391.7
P3 | +100mm_Back | 0 | 100 | 25 | 495.9 | 392.9
P3 | +100mm_Back | 0 | 100 | 26 | 497.7 | 388.6
P3 | +100mm_Back | 0 | 100 | 27 | 492.9 | 403.0
P3 | +100mm_Back | 0 | 100 | 28 | 492.3 | 389.2
P3 | +100mm_Back | 0 | 100 | 29 | 489.3 | 395.4
P3 | +100mm_Back | 0 | 100 | 30 | 504.3 | 392.1
P3 | +100mm_Back | 0 | 100 | 31 | 497.7 | 395.1
P3 | +100mm_Back | 0 | 100 | 32 | 491.7 | 384.4
P3 | +100mm_Back | 0 | 100 | 33 | 486.9 | 393.1
P3 | +100mm_Back | 0 | 100 | 34 | 495.1 | 388.1
P3 | +100mm_Back | 0 | 100 | 35 | 493.8 | 397.1
P3 | +100mm_Back | 0 | 100 | 36 | 492.2 | 382.7
P3 | +100mm_Back | 0 | 100 | 37 | 501.1 | 403.3
P3 | +100mm_Back | 0 | 100 | 38 | 486.5 | 398.3
P3 | +100mm_Back | 0 | 100 | 39 | 497.5 | 392.7
P3 | +100mm_Back | 0 | 100 | 40 | 493.2 | 400.4
P3 | +100mm_Back | 0 | 100 | 41 | 491.5 | 393.6
P3 | +100mm_Back | 0 | 100 | 42 | 491.2 | 396.1
P3 | +100mm_Back | 0 | 100 | 43 | 486.1 | 401.6
P3 | +100mm_Back | 0 | 100 | 44 | 492.4 | 387.7
P3 | +100mm_Back | 0 | 100 | 45 | 493.6 | 399.4
P3 | +100mm_Back | 0 | 100 | 46 | 494.1 | 397.1
P3 | +100mm_Back | 0 | 100 | 47 | 488.2 | 394.7
P3 | +100mm_Back | 0 | 100 | 48 | 489.8 | 399.2
P3 | +100mm_Back | 0 | 100 | 49 | 494.4 | 388.4
P3 | +100mm_Back | 0 | 100 | 50 | 501.2 | 389.1
P3 | +100mm_Back | 0 | 100 | 51 | 493.8 | 389.7
P3 | +100mm_Back | 0 | 100 | 52 | 488.3 | 391.2
P3 | +100mm_Back | 0 | 100 | 53 | 488.0 | 385.6
P3 | +100mm_Back | 0 | 100 | 54 | 494.3 | 396.5
P3 | +100mm_Back | 0 | 100 | 55 | 487.7 | 390.8
P3 | +100mm_Back | 0 | 100 | 56 | 498.1 | 388.9
P3 | +100mm_Back | 0 | 100 | 57 | 485.8 | 395.0
P3 | +100mm_Back | 0 | 100 | 58 | 495.6 | 395.7
P3 | +100mm_Back | 0 | 100 | 59 | 494.9 | 395.7
P3 | +100mm_Back | 0 | 100 | 60 | 493.4 | 390.0
P3 | +100mm_Back | 0 | 100 | 61 | 490.6 | 400.5
P3 | +100mm_Back | 0 | 100 | 62 | 492.7 | 397.0
P3 | +100mm_Back | 0 | 100 | 63 | 495.5 | 392.8
P3 | +100mm_Back | 0 | 100 | 64 | 498.0 | 392.9
P3 | +100mm_Back | 0 | 100 | 65 | 495.9 | 390.3
P3 | +100mm_Back | 0 | 100 | 66 | 498.2 | 391.5
P3 | +100mm_Back | 0 | 100 | 67 | 487.8 | 400.4
P3 | +100mm_Back | 0 | 100 | 68 | 491.6 | 392.5
P3 | +100mm_Back | 0 | 100 | 69 | 506.2 | 399.8
P3 | +100mm_Back | 0 | 100 | 70 | 482.1 | 394.3
P3 | +100mm_Back | 0 | 100 | 71 | 489.1 | 389.3
P3 | +100mm_Back | 0 | 100 | 72 | 502.0 | 388.7
P3 | +100mm_Back | 0 | 100 | 73 | 492.8 | 398.0
P3 | +100mm_Back | 0 | 100 | 74 | 494.6 | 394.0
P3 | +100mm_Back | 0 | 100 | 75 | 485.5 | 389.9
P3 | +100mm_Back | 0 | 100 | 76 | 504.5 | 390.9
P3 | +100mm_Back | 0 | 100 | 77 | 488.0 | 395.5
P3 | +100mm_Back | 0 | 100 | 78 | 487.7 | 390.0
P3 | +100mm_Back | 0 | 100 | 79 | 487.7 | 383.8
P3 | +100mm_Back | 0 | 100 | 80 | 488.7 | 387.7
P3 | +100mm_Back | 0 | 100 | 81 | 483.1 | 394.6
P3 | +100mm_Back | 0 | 100 | 82 | 493.0 | 395.4
P3 | +100mm_Back | 0 | 100 | 83 | 495.0 | 405.4
P3 | +100mm_Back | 0 | 100 | 84 | 489.7 | 399.7
P3 | +100mm_Back | 0 | 100 | 85 | 496.8 | 388.3
P3 | +100mm_Back | 0 | 100 | 86 | 491.6 | 382.4
P3 | +100mm_Back | 0 | 100 | 87 | 511.3 | 389.1
P3 | +100mm_Back | 0 | 100 | 88 | 489.8 | 398.1
P3 | +100mm_Back | 0 | 100 | 89 | 487.7 | 381.1
P3 | +100mm_Back | 0 | 100 | 90 | 486.9 | 388.7
P3 | +100mm_Back | 0 | 100 | 91 | 488.2 | 392.8
P3 | +100mm_Back | 0 | 100 | 92 | 493.6 | 386.1
P3 | +100mm_Back | 0 | 100 | 93 | 493.2 | 395.7
P3 | +100mm_Back | 0 | 100 | 94 | 484.6 | 392.9
P3 | +100mm_Back | 0 | 100 | 95 | 487.5 | 397.7
P3 | +100mm_Back | 0 | 100 | 96 | 494.5 | 394.2
P3 | +100mm_Back | 0 | 100 | 97 | 498.7 | 394.0
P3 | +100mm_Back | 0 | 100 | 98 | 501.0 | 397.8
P3 | +100mm_Back | 0 | 100 | 99 | 492.3 | 374.7
P3 | +100mm_Back | 0 | 100 | 100 | 488.1 | 390.4
P4 | +60R_+70B | 60 | 70 | 1 | 431.3 | 419.6
P4 | +60R_+70B | 60 | 70 | 2 | 424.6 | 424.8
P4 | +60R_+70B | 60 | 70 | 3 | 431.6 | 427.8
P4 | +60R_+70B | 60 | 70 | 4 | 423.7 | 425.3
P4 | +60R_+70B | 60 | 70 | 5 | 428.4 | 423.0
P4 | +60R_+70B | 60 | 70 | 6 | 434.3 | 421.2
P4 | +60R_+70B | 60 | 70 | 7 | 427.1 | 434.7
P4 | +60R_+70B | 60 | 70 | 8 | 433.1 | 423.4
P4 | +60R_+70B | 60 | 70 | 9 | 428.7 | 421.5
P4 | +60R_+70B | 60 | 70 | 10 | 428.5 | 430.1
P4 | +60R_+70B | 60 | 70 | 11 | 434.9 | 417.7
P4 | +60R_+70B | 60 | 70 | 12 | 445.0 | 425.6
P4 | +60R_+70B | 60 | 70 | 13 | 437.4 | 423.1
P4 | +60R_+70B | 60 | 70 | 14 | 436.2 | 422.5
P4 | +60R_+70B | 60 | 70 | 15 | 430.9 | 435.0
P4 | +60R_+70B | 60 | 70 | 16 | 432.5 | 412.0
P4 | +60R_+70B | 60 | 70 | 17 | 435.4 | 421.7
P4 | +60R_+70B | 60 | 70 | 18 | 428.3 | 422.1
P4 | +60R_+70B | 60 | 70 | 19 | 429.5 | 418.9
P4 | +60R_+70B | 60 | 70 | 20 | 430.5 | 416.7
P4 | +60R_+70B | 60 | 70 | 21 | 440.3 | 417.9
P4 | +60R_+70B | 60 | 70 | 22 | 429.9 | 424.2
P4 | +60R_+70B | 60 | 70 | 23 | 426.1 | 424.2
P4 | +60R_+70B | 60 | 70 | 24 | 428.8 | 425.7
P4 | +60R_+70B | 60 | 70 | 25 | 431.4 | 416.3
P4 | +60R_+70B | 60 | 70 | 26 | 432.4 | 426.1
P4 | +60R_+70B | 60 | 70 | 27 | 440.1 | 419.9
P4 | +60R_+70B | 60 | 70 | 28 | 438.2 | 426.1
P4 | +60R_+70B | 60 | 70 | 29 | 431.6 | 412.7
P4 | +60R_+70B | 60 | 70 | 30 | 428.8 | 428.7
P4 | +60R_+70B | 60 | 70 | 31 | 428.5 | 424.0
P4 | +60R_+70B | 60 | 70 | 32 | 435.0 | 411.2
P4 | +60R_+70B | 60 | 70 | 33 | 422.4 | 412.0
P4 | +60R_+70B | 60 | 70 | 34 | 419.8 | 428.4
P4 | +60R_+70B | 60 | 70 | 35 | 431.9 | 429.7
P4 | +60R_+70B | 60 | 70 | 36 | 421.6 | 426.8
P4 | +60R_+70B | 60 | 70 | 37 | 419.4 | 422.2
P4 | +60R_+70B | 60 | 70 | 38 | 431.9 | 425.7
P4 | +60R_+70B | 60 | 70 | 39 | 434.3 | 426.4
P4 | +60R_+70B | 60 | 70 | 40 | 437.2 | 423.2
P4 | +60R_+70B | 60 | 70 | 41 | 431.2 | 415.9
P4 | +60R_+70B | 60 | 70 | 42 | 430.8 | 423.6
P4 | +60R_+70B | 60 | 70 | 43 | 435.9 | 429.5
P4 | +60R_+70B | 60 | 70 | 44 | 435.0 | 424.0
P4 | +60R_+70B | 60 | 70 | 45 | 432.3 | 428.2
P4 | +60R_+70B | 60 | 70 | 46 | 430.3 | 429.8
P4 | +60R_+70B | 60 | 70 | 47 | 432.8 | 430.6
P4 | +60R_+70B | 60 | 70 | 48 | 434.0 | 417.6
P4 | +60R_+70B | 60 | 70 | 49 | 448.5 | 421.3
P4 | +60R_+70B | 60 | 70 | 50 | 438.1 | 411.7
P4 | +60R_+70B | 60 | 70 | 51 | 435.2 | 426.8
P4 | +60R_+70B | 60 | 70 | 52 | 435.4 | 427.4
P4 | +60R_+70B | 60 | 70 | 53 | 431.7 | 430.3
P4 | +60R_+70B | 60 | 70 | 54 | 434.7 | 422.9
P4 | +60R_+70B | 60 | 70 | 55 | 426.0 | 423.3
P4 | +60R_+70B | 60 | 70 | 56 | 430.9 | 428.3
P4 | +60R_+70B | 60 | 70 | 57 | 432.6 | 424.1
P4 | +60R_+70B | 60 | 70 | 58 | 446.4 | 418.0
P4 | +60R_+70B | 60 | 70 | 59 | 434.8 | 423.7
P4 | +60R_+70B | 60 | 70 | 60 | 444.3 | 420.3
P4 | +60R_+70B | 60 | 70 | 61 | 434.3 | 426.9
P4 | +60R_+70B | 60 | 70 | 62 | 432.0 | 423.2
P4 | +60R_+70B | 60 | 70 | 63 | 430.0 | 417.2
P4 | +60R_+70B | 60 | 70 | 64 | 425.8 | 417.9
P4 | +60R_+70B | 60 | 70 | 65 | 440.6 | 422.4
P4 | +60R_+70B | 60 | 70 | 66 | 431.6 | 421.0
P4 | +60R_+70B | 60 | 70 | 67 | 430.2 | 431.1
P4 | +60R_+70B | 60 | 70 | 68 | 435.2 | 431.7
P4 | +60R_+70B | 60 | 70 | 69 | 432.8 | 425.9
P4 | +60R_+70B | 60 | 70 | 70 | 435.7 | 425.2
P4 | +60R_+70B | 60 | 70 | 71 | 434.7 | 426.6
P4 | +60R_+70B | 60 | 70 | 72 | 433.4 | 432.8
P4 | +60R_+70B | 60 | 70 | 73 | 436.4 | 432.3
P4 | +60R_+70B | 60 | 70 | 74 | 438.8 | 419.8
P4 | +60R_+70B | 60 | 70 | 75 | 437.4 | 421.5
P4 | +60R_+70B | 60 | 70 | 76 | 436.1 | 429.2
P4 | +60R_+70B | 60 | 70 | 77 | 441.8 | 425.6
P4 | +60R_+70B | 60 | 70 | 78 | 436.8 | 416.4
P4 | +60R_+70B | 60 | 70 | 79 | 435.8 | 424.7
P4 | +60R_+70B | 60 | 70 | 80 | 432.5 | 426.1
P4 | +60R_+70B | 60 | 70 | 81 | 426.6 | 424.1
P4 | +60R_+70B | 60 | 70 | 82 | 442.3 | 423.2
P4 | +60R_+70B | 60 | 70 | 83 | 430.0 | 427.3
P4 | +60R_+70B | 60 | 70 | 84 | 427.2 | 423.2
P4 | +60R_+70B | 60 | 70 | 85 | 428.3 | 430.9
P4 | +60R_+70B | 60 | 70 | 86 | 439.6 | 421.5
P4 | +60R_+70B | 60 | 70 | 87 | 429.1 | 423.2
P4 | +60R_+70B | 60 | 70 | 88 | 424.2 | 434.5
P4 | +60R_+70B | 60 | 70 | 89 | 438.9 | 417.4
P4 | +60R_+70B | 60 | 70 | 90 | 427.7 | 431.0
P4 | +60R_+70B | 60 | 70 | 91 | 433.0 | 419.0
P4 | +60R_+70B | 60 | 70 | 92 | 435.9 | 429.4
P4 | +60R_+70B | 60 | 70 | 93 | 426.3 | 421.5
P4 | +60R_+70B | 60 | 70 | 94 | 433.2 | 434.9
P4 | +60R_+70B | 60 | 70 | 95 | 426.8 | 416.8
P4 | +60R_+70B | 60 | 70 | 96 | 431.2 | 419.4
P4 | +60R_+70B | 60 | 70 | 97 | 437.0 | 423.9
P4 | +60R_+70B | 60 | 70 | 98 | 430.0 | 432.0
P4 | +60R_+70B | 60 | 70 | 99 | 427.6 | 417.2
P4 | +60R_+70B | 60 | 70 | 100 | 442.9 | 415.3

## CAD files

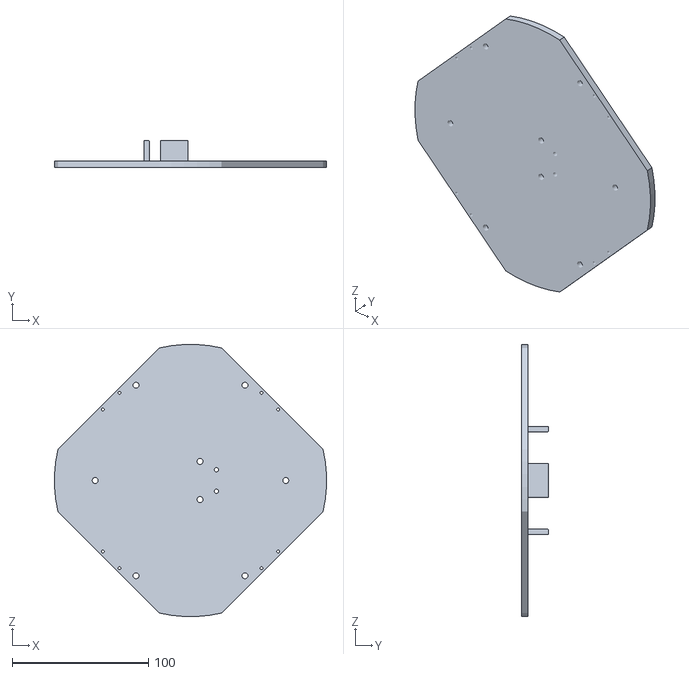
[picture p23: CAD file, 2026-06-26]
sld/Bottom V3.STL
199.8 x 20.0 x 199.8

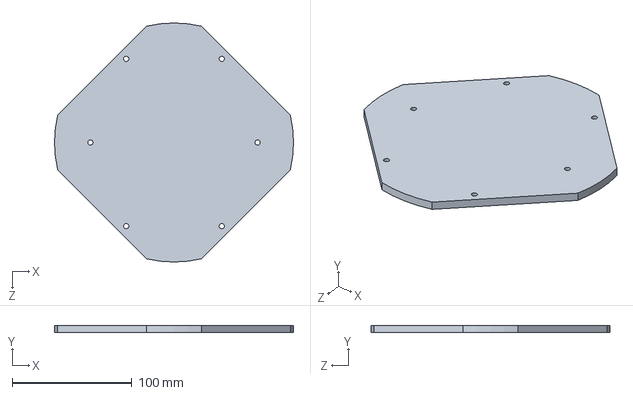
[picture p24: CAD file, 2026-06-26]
sld/Bottom.SLDPRT
200.0 x 6.00 x 200.0 mm

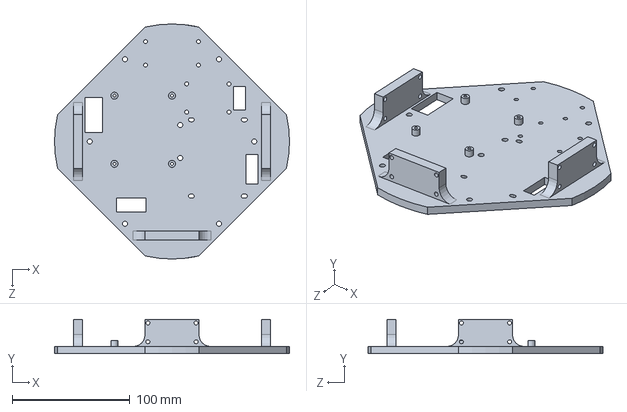
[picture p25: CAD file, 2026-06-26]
sld/Top.SLDPRT
200.0 x 29.0 x 200.0 mm

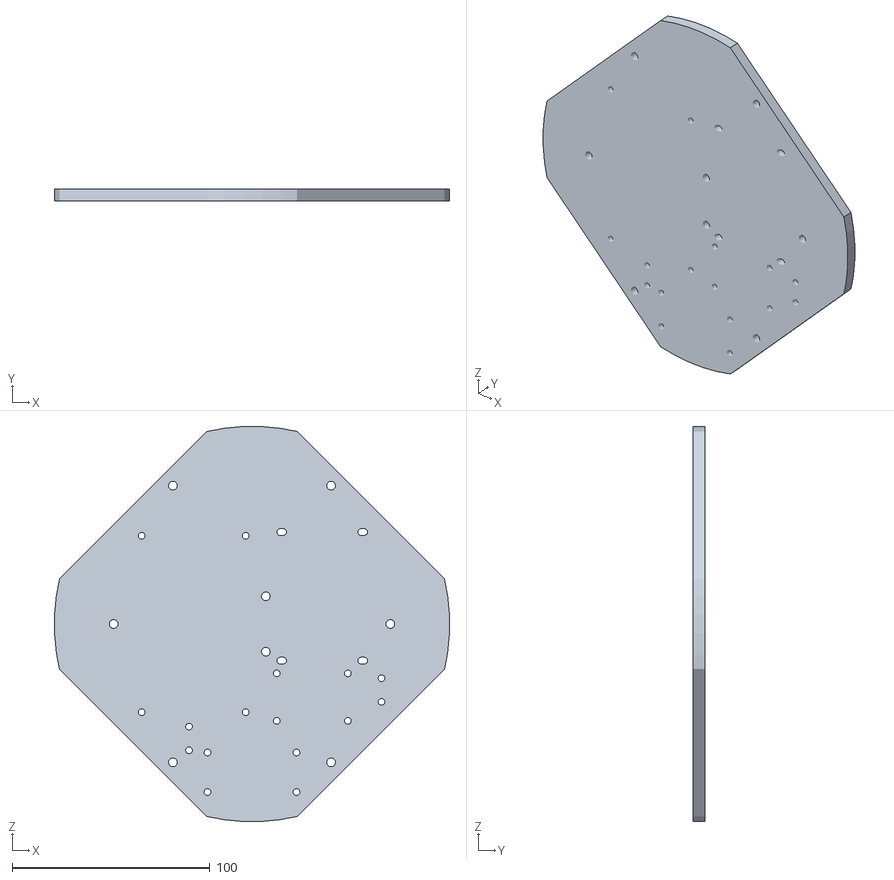
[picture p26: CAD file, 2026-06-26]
sld/TopTest.STL
199.8 x 6.00 x 199.8

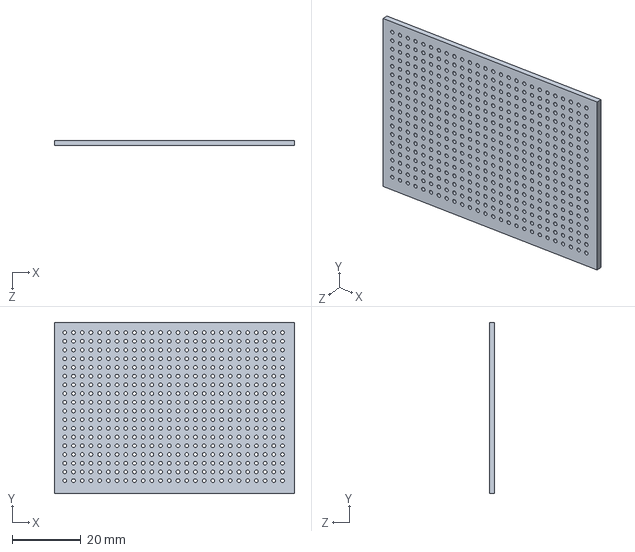
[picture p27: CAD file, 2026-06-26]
sld/perf.SLDPRT
70.0 x 50.0 x 1.60 mm

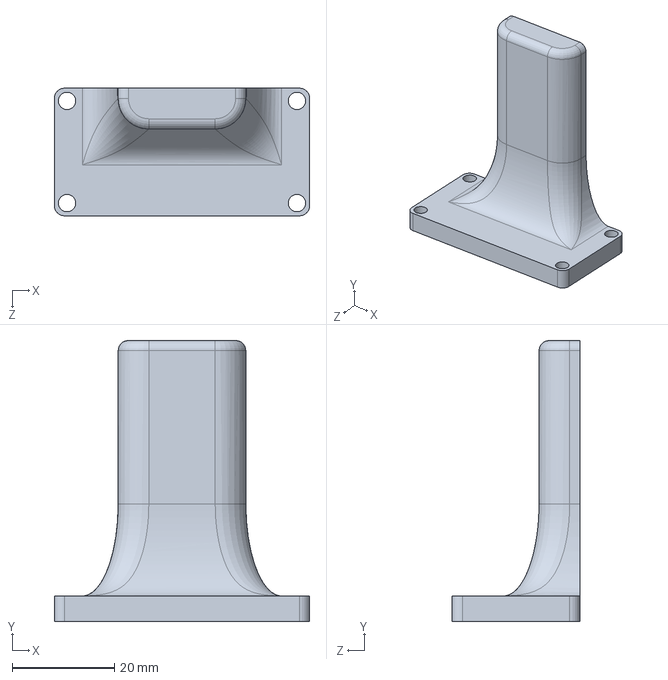
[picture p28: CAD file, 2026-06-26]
sld/camera stand.SLDPRT
50.0 x 55.0 x 25.0 mm

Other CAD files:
sld/TopV3.STL
sld/Bottom V2.SLDPRT
sld/TopV2.STL
sld/Bottom V2.STL
sld/Top.3mf
sld/Top.STL
sld/camera stand.STL
sld/perf.STL

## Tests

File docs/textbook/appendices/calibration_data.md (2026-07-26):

# Calibration Data

:::{admonition} Appendix status: Initial index
:class: status status-outline

Raw observations are preserved in the repository. Chapter prose must cite the
input file and distinguish raw measurements from derived parameters.
:::

## Encoder and motion calibration

| Artifact | Purpose | Current conclusion |
| --- | --- | --- |
| [`Week4 Trials.xlsx`](https://github.com/Tuomaaa/XDriveSLAMRover/blob/main/data/Week4%20Trials.xlsx) | Ground-truth motion trials | Supports the $\sqrt{2}$ translation correction; full uncertainty campaign pending |
| [`odometry.py`](https://github.com/Tuomaaa/XDriveSLAMRover/blob/main/ros2_ws/src/odometry.py) | Applied calibration constants | CPR 2779, all signs `-1`, rear encoder swap explicit |

## Ultrasonic calibration

| Artifact | Purpose | Current conclusion |
| --- | --- | --- |
| [`bench_calibration.csv`](https://github.com/Tuomaaa/XDriveSLAMRover/blob/main/data/ultrasonic/bench_calibration.csv) | Raw two-sensor samples | 2 sensors x 4 distances x 100 samples |
| [`bench_summary.csv`](https://github.com/Tuomaaa/XDriveSLAMRover/blob/main/data/ultrasonic/bench_summary.csv) | Group statistics | Supports $\sigma(d)=0.0017+0.0078d$ m |
| [`map_validation.csv`](https://github.com/Tuomaaa/XDriveSLAMRover/blob/main/data/ultrasonic/map_validation.csv) | Map/sensor end-to-end test | True pose outscored shifted poses in all four positions |

## Reproducibility rule

A parameter belongs in a completed chapter only when its acquisition method,
units, sample count, raw input, transformation, and verification result are all
available. Theoretical defaults must remain labeled as theoretical.

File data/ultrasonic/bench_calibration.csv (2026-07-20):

sensor | true_distance_mm | sample_id | reading_mm
Right | 100 | 1 | 101.7
Right | 100 | 2 | 99.5
Right | 100 | 3 | 103.4
Right | 100 | 4 | 102.7
Right | 100 | 5 | 105.9
Right | 100 | 6 | 103.4
Right | 100 | 7 | 100.8
Right | 100 | 8 | 99.1
Right | 100 | 9 | 104.1
Right | 100 | 10 | 102.0
Right | 100 | 11 | 102.5
Right | 100 | 12 | 101.3
Right | 100 | 13 | 98.2
Right | 100 | 14 | 104.7
Right | 100 | 15 | 103.8
Right | 100 | 16 | 103.2
Right | 100 | 17 | 104.2
Right | 100 | 18 | 99.9
Right | 100 | 19 | 107.1
Right | 100 | 20 | 102.0
Right | 100 | 21 | 103.5
Right | 100 | 22 | 104.4
Right | 100 | 23 | 96.5
Right | 100 | 24 | 106.4
Right | 100 | 25 | 102.8
Right | 100 | 26 | 98.9
Right | 100 | 27 | 101.9
Right | 100 | 28 | 108.8
Right | 100 | 29 | 102.1
Right | 100 | 30 | 99.5
Right | 100 | 31 | 102.3
Right | 100 | 32 | 103.5
Right | 100 | 33 | 101.3
Right | 100 | 34 | 101.3
Right | 100 | 35 | 105.3
Right | 100 | 36 | 104.6
Right | 100 | 37 | 102.7
Right | 100 | 38 | 102.5
Right | 100 | 39 | 103.0
Right | 100 | 40 | 101.7
Right | 100 | 41 | 102.7
Right | 100 | 42 | 103.0
Right | 100 | 43 | 106.0
Right | 100 | 44 | 100.1
Right | 100 | 45 | 104.8
Right | 100 | 46 | 106.4
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

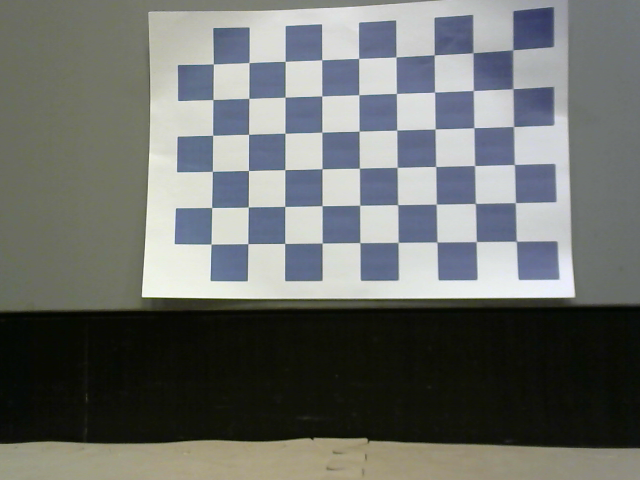
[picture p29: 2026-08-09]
ros2_ws/src/calibration_images/calib_001.png

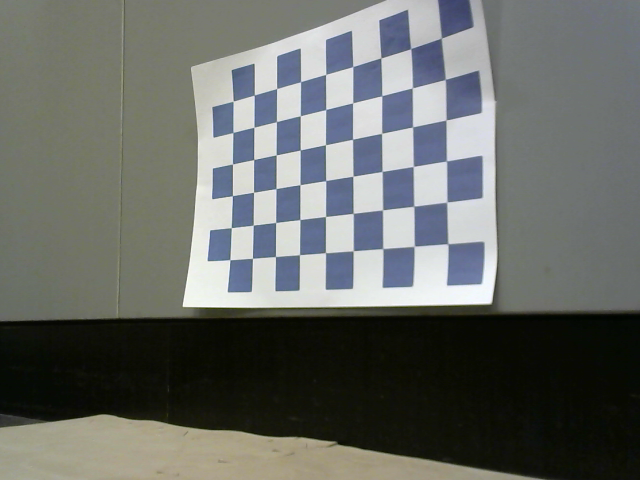
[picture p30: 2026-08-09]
ros2_ws/src/calibration_images/calib_004.png

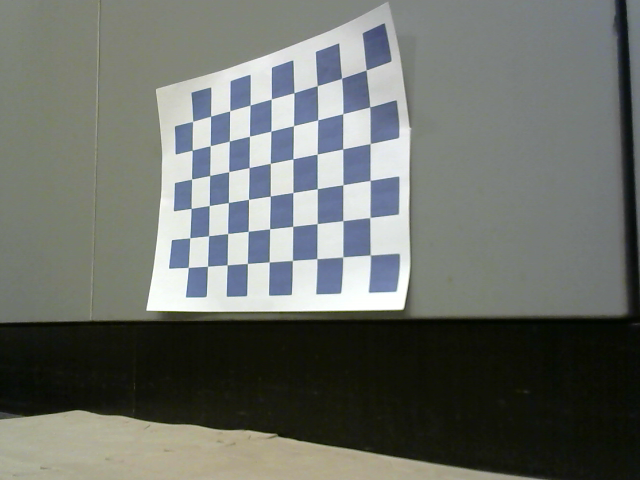
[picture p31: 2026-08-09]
ros2_ws/src/calibration_images/calib_005.png

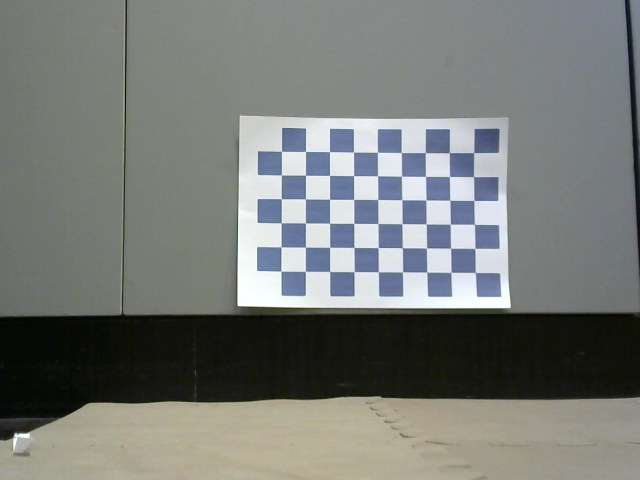
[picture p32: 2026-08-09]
ros2_ws/src/calibration_images/calib_010.png

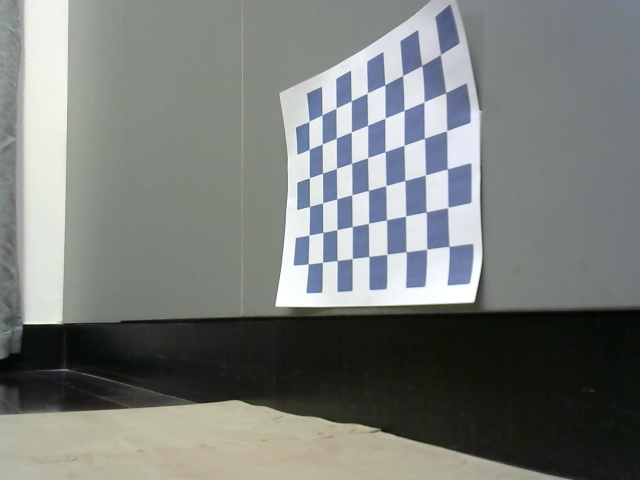
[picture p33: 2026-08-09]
ros2_ws/src/calibration_images/calib_006.png

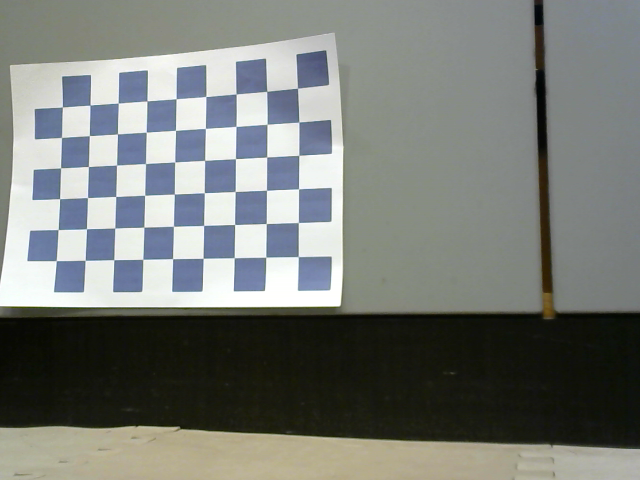
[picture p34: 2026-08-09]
ros2_ws/src/calibration_images/calib_003.png

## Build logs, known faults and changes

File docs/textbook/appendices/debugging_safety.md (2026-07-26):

# Safety and Debugging Index

This appendix makes failure evidence discoverable without hiding it behind the
final implementation. Each entry links to the week where its physical symptom,
diagnosis, and repair belong.

## Power and hardware safety

- {ref}`Two destructive electrical incidents <power-rail-incident>` - two
  unresolved shorts destroyed two STM32 boards, three TB6612 modules, and one
  ST-Link in total. The notes separate observed damage from unconfirmed root
  cause.
- Raspberry Pi GPIO is not 5 V tolerant; the PS2 receiver uses 3.3 V logic.
- The TJA1050 module still requires its documented 5 V supply for valid CAN
  transceiver levels even though the MCP2515 logic side is lower voltage.
- A separate Raspberry Pi supply branch reduces exposure but is not necessarily
  galvanically isolated; shared grounds and communication paths still matter.
- High- and low-voltage harnesses must be physically separated before probing.
- Continuity checks are only triage. Reintroduce repaired hardware one module at
  a time with current limiting.

## Firmware and transport

- {ref}`CAN driver and parser failures <can-stack-failures>` - incorrect
  `TXBnCTRL` addressing, missing `can_frame` definitions, CMake regeneration,
  and Python capture-pattern behavior.
- CubeMX failed to persist TIM3 `ENCODER_MODE_TI12`; the `.ioc` required an
  explicit text correction or one encoder would have one-quarter resolution.
- The ST VS Code extension may report a regenerated project as corrupted;
  opening a clean CubeMX-generated project is the recorded workaround.
- Raspberry Pi Wi-Fi may reach `UP` without a DHCP IPv4 address. CAN and GPIO
  testing remain independent of that failure.

## Motion and control

- {ref}`Rear encoder harness swap <encoder-map-failure>` - forward motion was
  correct while lateral and angular channels exchanged roles.
- {ref}`PID positive-feedback runaway <pid-runaway>` - all raw encoder signs
  opposed commanded forward motion.
- {ref}`Heartbeat stop overwritten <heartbeat-overwrite>` - normal control
  restored PWM immediately after the stop call.
- {ref}`Missing 45-degree projection <translation-scale-failure>` - both
  translation axes measured low while rotation scale remained plausible.
- {ref}`REP-103 frame mirror <frame-mirror-failure>` - lateral and angular
  outputs required an output-frame correction, not retuned encoder signs.
- STM32 still uses theoretical CPR 2800 for the disabled PID branch while ROS
  2 odometry uses calibrated CPR 2779. The mismatch is intentional and should
  not be "fixed" without revisiting that decision.
- Open-loop motor mismatch can create physical yaw during nominal translation;
  ground-truth analysis must separate this behavior from odometry math errors.

## Sensing and localization

- {ref}`Ultrasonic invalid readings <ultrasonic-invalids>` - invalid and
  saturated returns remain explicit mixture-model cases.
- {ref}`MCL design corrections <mcl-design-corrections>` - holonomic motion,
  heading diversity, observability, and ground-truth comparison constraints.

## Documentation rule

Expanded chapters should retain the full evidence chain:
**symptom -> competing hypotheses -> discriminating test -> root cause ->
repair -> regression test**. Removing the failed path would make the hardware
reproduction less reliable.

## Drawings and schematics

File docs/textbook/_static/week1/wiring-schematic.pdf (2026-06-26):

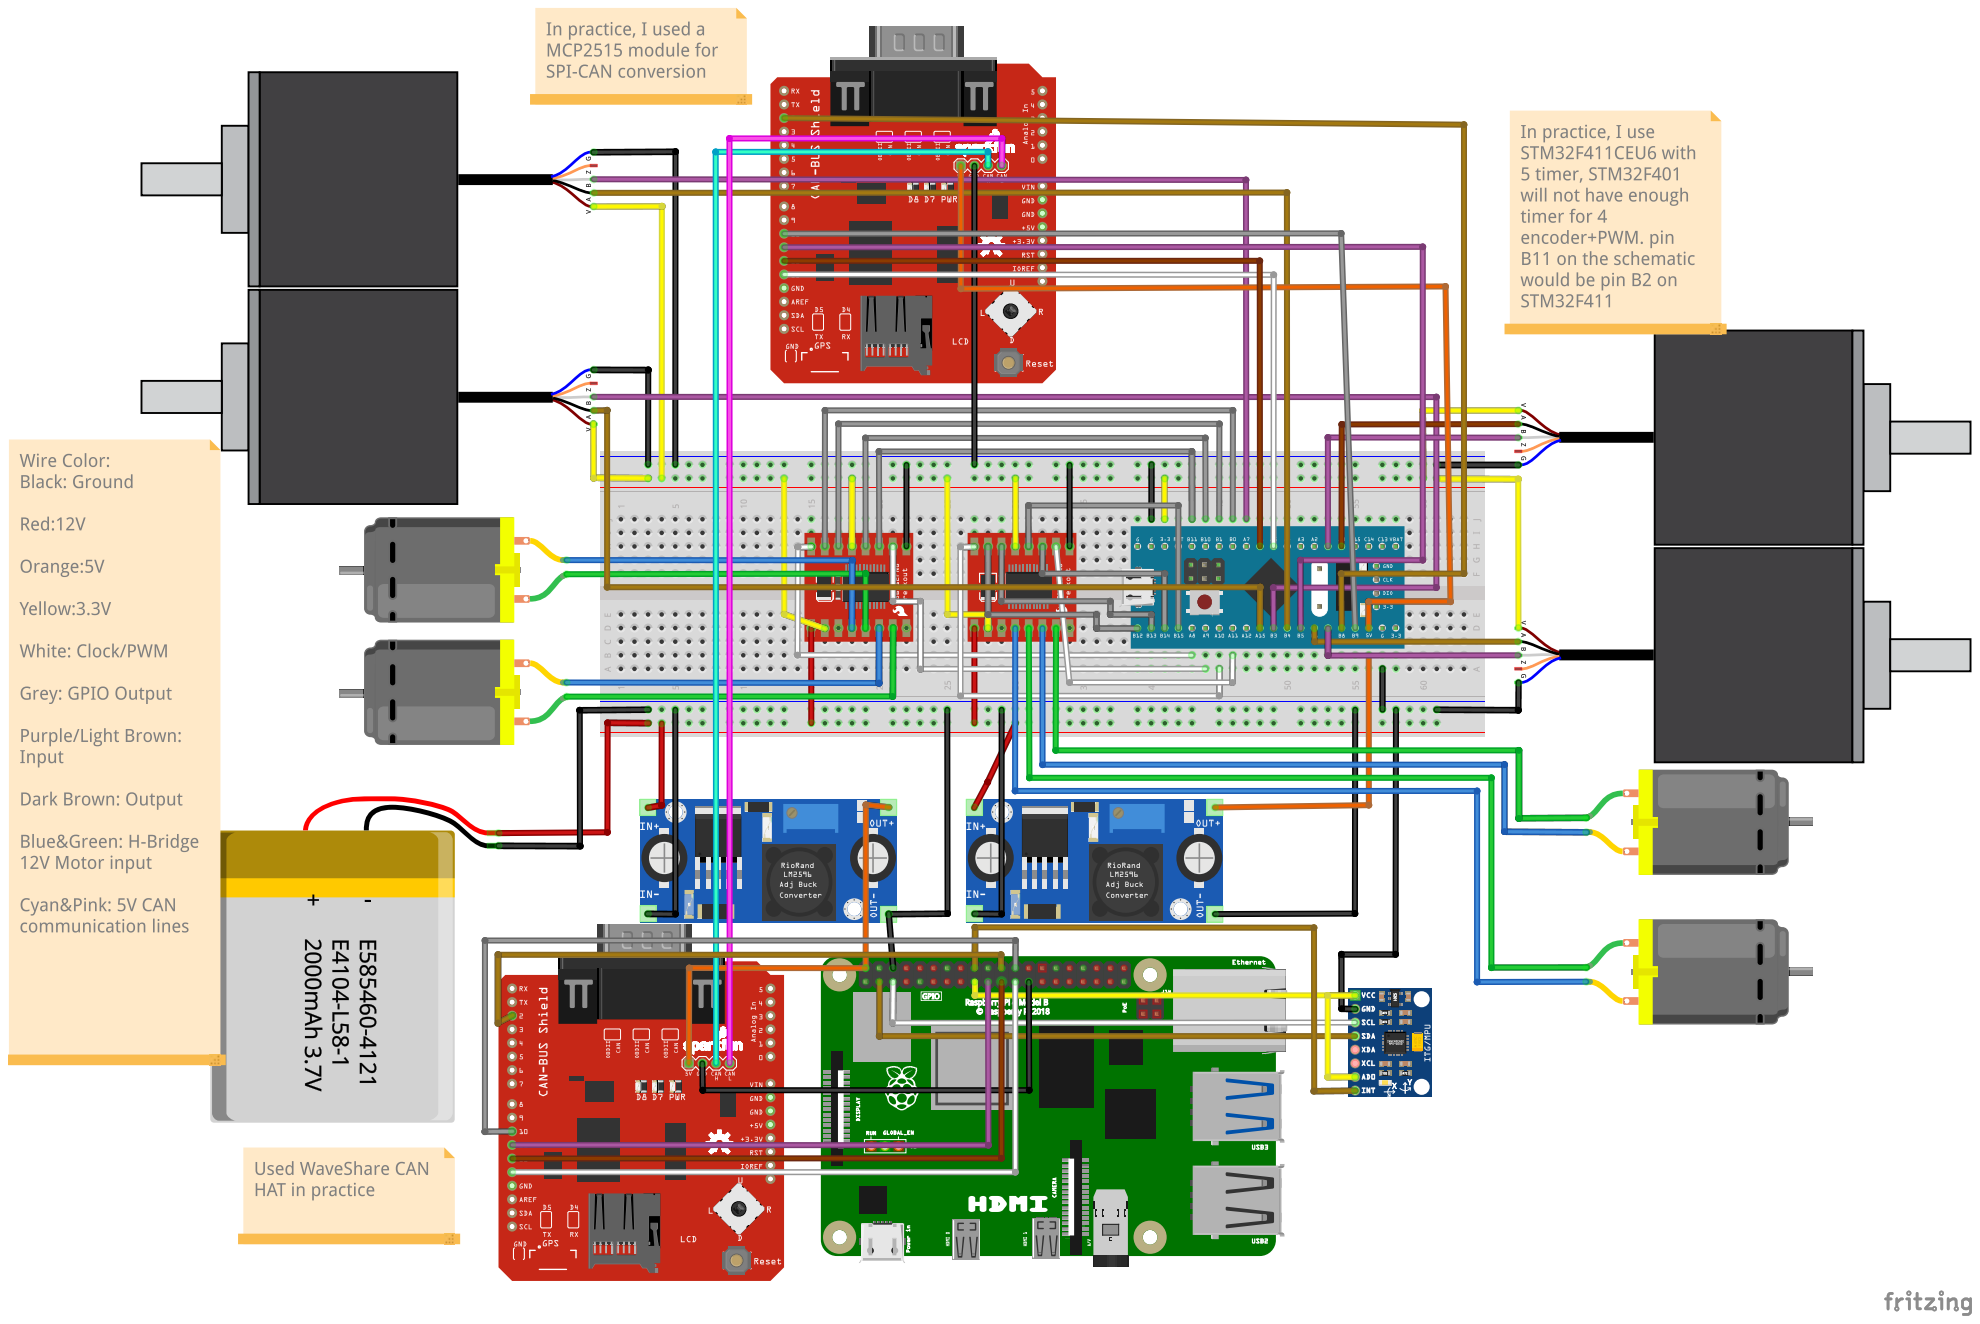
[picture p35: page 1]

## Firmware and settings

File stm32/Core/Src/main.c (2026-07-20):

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
/* Includes ------------------------------------------------------------------*/
#include "main.h"

/* USER CODE BEGIN Includes */
#include "mcp2515.h"
#include "can.h"
#include "hc_sr04.h"
#include <string.h>
/* USER CODE END Includes */

/* USER CODE BEGIN PTD */
typedef struct {
  float kp, ki, kd;
  float integral;
  float prev_error;
} PID_t;

typedef struct {
  TIM_HandleTypeDef* enc_tim;   // encoder timer
  uint32_t pwm_ch;              // TIM1 PWM channel
  uint16_t fwd_pin;             // direction forward
  uint16_t rev_pin;             // direction reverse
  int16_t target_rpm;           // from CAN 0x100
  int32_t cum_ticks;            // cumulative encoder ticks
  uint16_t prev_cnt;            // previous raw counter (for 16-bit overflow)
  uint8_t is_32bit;             // 1=32-bit timer, 0=16-bit
  PID_t pid;
} Motor_t;

// ── Motor index <-> physical wheel position ──
// This is the single source of truth for which motor index corresponds
// to which physical corner of the x-drive chassis. It MUST stay in sync
// with:
//   - odometry.py's MOTOR_MAP (RPi side, {0:"fl",1:"fr",2:"rl",3:"rr"})
//   - ps2_drive_test.py's inverse-kinematics ordering (m0=fl,m1=fr,m2=rl,m3=rr)
//   - CAN 0x100 (velocity command) / 0x200,0x201 (encoder feedback) payload order
// Confirmed against physical wiring 2026-07-03: see PROJECT_STATE.md decision log.
typedef enum {
  MOTOR_FL = 0,  // front-left  -> TIM2 (32-bit encoder, PA15/PB3)
  MOTOR_FR = 1,  // front-right -> TIM3 (16-bit encoder, PB4/PA7)
  MOTOR_RL = 2,  // rear-left   -> TIM4 (16-bit encoder, PB6/PB7)
  MOTOR_RR = 3,  // rear-right  -> TIM5 (32-bit encoder, PA0/PA1)
} MotorPosition;
/* USER CODE END PTD */

/* USER CODE BEGIN PD */
#define NUM_MOTORS       4
#define PWM_PERIOD       4999
#define MAX_RPM          300

// Motor control mode:
//   0 = open-loop  -> joystick target RPM maps straight to PWM duty. No
//       encoder feedback in the control path, so the reversed encoders
//       can't cause PID runaway. This is what the RC + odometry-calibration
//       phase needs; odometry reads encoders directly and does NOT depend
//       on closed-loop speed control.
//   1 = closed-loop speed PID (see pid_compute + ENC_SIGN). Re-enable later
//       for autonomous cmd_vel driving. The PID code is retained below.
#define USE_PID          0

// Encoder counts per output-shaft revolution
// GA12-N20: 7 PPR motor × gear_ratio × 4 (TI12 mode)
// Adjust this after measuring your actual encoder!
#define ENCODER_CPR      2800

// PID gains (tune these on real hardware) -- only used when USE_PID = 1
#define PID_KP           8.0f
#define PID_KI           2.0f
#define PID_KD           0.1f

// Timing
#define PID_INTERVAL_MS  20     // control + encoder send rate (20ms = 50Hz)
#define HEARTBEAT_TIMEOUT_MS 200

// CAN IDs
#define CAN_ID_VEL_CMD   0x100   // payload: int16 target RPM x4, order = [MOTOR_FL, MOTOR_FR, MOTOR_RL, MOTOR_RR]
#define CAN_ID_ENCODER_0 0x200   // payload: int32 cum_ticks x2 = [MOTOR_FL, MOTOR_FR]
#define CAN_ID_ENCODER_1 0x201   // payload: int32 cum_ticks x2 = [MOTOR_RL, MOTOR_RR]
#define CAN_ID_ULTRASONIC 0x202  // payload: right_mm, back_mm, validity status
#define CAN_ID_HEARTBEAT 0x300
/* USER CODE END PD */

SPI_HandleTypeDef hspi1;

TIM_HandleTypeDef htim1;
TIM_HandleTypeDef htim2;
TIM_HandleTypeDef htim3;
TIM_HandleTypeDef htim4;
TIM_HandleTypeDef htim5;
TIM_HandleTypeDef htim9;

/* USER CODE BEGIN PV */
Motor_t motors[NUM_MOTORS];
uint32_t last_heartbeat = 0;
uint32_t last_pid_time = 0;

#if USE_PID
// Encoder direction vs. motor-command direction, per motor index.
// CALIBRATED 2026-07-04: all four encoders count DOWN when the motor is
// driven forward (target_rpm > 0). Without this correction the PID uses
// the raw (reversed) count as feedback, which turns speed control into
// POSITIVE feedback and makes the motors run away to full speed on the
// slightest disturbance. This sign is ONLY applied to the PID feedback;
// the cumulative ticks sent over CAN (0x200/0x201) stay raw, so the RPi
// odometry keeps its own ENCODER_SIGN = -1 and needs no change.
static const int8_t ENC_SIGN[NUM_MOTORS] = {-1, -1, -1, -1};
#endif
/* USER CODE END PV */

void SystemClock_Config(void);
static void MX_GPIO_Init(void);
static void MX_SPI1_Init(void);
static void MX_TIM1_Init(void);
static void MX_TIM2_Init(void);
static void MX_TIM3_Init(void);
static void MX_TIM4_Init(void);
static void MX_TIM5_Init(void);
static void MX_TIM9_Init(void);
/* USER CODE BEGIN 0 */

// ── Read encoder ticks (handles 16-bit overflow) ──
void encoder_update(Motor_t* m) {
  if (m->is_32bit) {
    m->cum_ticks = (int32_t)__HAL_TIM_GET_COUNTER(m->enc_tim);
  } else {
    uint16_t cnt = (uint16_t)__HAL_TIM_GET_COUNTER(m->enc_tim);
    int16_t delta = (int16_t)(cnt - m->prev_cnt);
    m->cum_ticks += delta;
    m->prev_cnt = cnt;
  }
}

#if USE_PID
// ── PID compute: returns PWM duty (signed, +=forward) ──
// Retained for the future closed-loop phase; compiled only when USE_PID=1.
float pid_compute(PID_t* pid, float target, float actual, float dt) {
  float error = target - actual;
  pid->integral += error * dt;

  // Anti-windup: clamp integral
  if (pid->integral > 500.0f) pid->integral = 500.0f;
  if (pid->integral < -500.0f) pid->integral = -500.0f;

  float derivative = (dt > 0.0f) ? (error - pid->prev_error) / dt : 0.0f;
  pid->prev_error = error;

  return pid->kp * error + pid->ki * pid->integral + pid->kd * derivative;
}
#endif

// ── Set motor direction and PWM ──
void motor_set_pwm(Motor_t* m, int32_t duty) {
  if (duty > 0) {
    HAL_GPIO_WritePin(GPIOB, m->fwd_pin, GPIO_PIN_SET);
    HAL_GPIO_WritePin(GPIOB, m->rev_pin, GPIO_PIN_RESET);
  } else if (duty < 0) {
    HAL_GPIO_WritePin(GPIOB, m->fwd_pin, GPIO_PIN_RESET);
    HAL_GPIO_WritePin(GPIOB, m->rev_pin, GPIO_PIN_SET);
    duty = -duty;
  } else {
    HAL_GPIO_WritePin(GPIOB, m->fwd_pin, GPIO_PIN_RESET);
    HAL_GPIO_WritePin(GPIOB, m->rev_pin, GPIO_PIN_RESET);
  }
  if (duty > PWM_PERIOD) duty = PWM_PERIOD;
  __HAL_TIM_SET_COMPARE(&htim1, m->pwm_ch, (uint32_t)duty);
}

// ── Stop all motors ──
void motors_stop(void) {
  for (int i = 0; i < NUM_MOTORS; i++) {
    motors[i].target_rpm = 0;
    motor_set_pwm(&motors[i], 0);
  }
}

/* USER CODE END 0 */

/**
  * @brief  The application entry point.
  * @retval int
  */
int main(void)
{

  /* MCU Configuration--------------------------------------------------------*/

  /* Reset of all peripherals, Initializes the Flash interface and the Systick. */
  HAL_Init();

  /* Configure the system clock */
  SystemClock_Config();

  /* Initialize all configured peripherals */
  MX_GPIO_Init();
  MX_SPI1_Init();
  MX_TIM1_Init();
  MX_TIM2_Init();
  MX_TIM3_Init();
  MX_TIM4_Init();
  MX_TIM5_Init();
  MX_TIM9_Init();
  /* USER CODE BEGIN 2 */

  // ── Motor config table ──
  // Indexed by MotorPosition (see typedef above) -- NOT arbitrary order.
  // Wiring confirmed 2026-07-03: TIM2=FL, TIM3=FR, TIM4=RL, TIM5=RR.
  motors[MOTOR_FL] = (Motor_t){&htim2, TIM_CHANNEL_1, GPIO_PIN_1,  GPIO_PIN_0,  0, 0, 0, 1, {PID_KP,PID_KI,PID_KD, 0,0}};
  motors[MOTOR_FR] = (Motor_t){&htim3, TIM_CHANNEL_2, GPIO_PIN_10, GPIO_PIN_2,  0, 0, 0, 0, {PID_KP,PID_KI,PID_KD, 0,0}};
  motors[MOTOR_RL] = (Motor_t){&htim4, TIM_CHANNEL_3, GPIO_PIN_12, GPIO_PIN_13, 0, 0, 0, 0, {PID_KP,PID_KI,PID_KD, 0,0}};
  motors[MOTOR_RR] = (Motor_t){&htim5, TIM_CHANNEL_4, GPIO_PIN_14, GPIO_PIN_15, 0, 0, 0, 1, {PID_KP,PID_KI,PID_KD, 0,0}};

  // ── Start 4 encoder timers ──
  HAL_TIM_Encoder_Start(&htim2, TIM_CHANNEL_ALL);
  HAL_TIM_Encoder_Start(&htim3, TIM_CHANNEL_ALL);
  HAL_TIM_Encoder_Start(&htim4, TIM_CHANNEL_ALL);
  HAL_TIM_Encoder_Start(&htim5, TIM_CHANNEL_ALL);

  // ── Start 4 PWM channels (duty=0) ──
  HAL_TIM_PWM_Start(&htim1, TIM_CHANNEL_1);
  HAL_TIM_PWM_Start(&htim1, TIM_CHANNEL_2);
  HAL_TIM_PWM_Start(&htim1, TIM_CHANNEL_3);
  HAL_TIM_PWM_Start(&htim1, TIM_CHANNEL_4);

  // ── MCP2515 init ──
  CAN_Error err;
  err = MCP_reset();
  if (err == ERROR_OK) err = MCP_setBitrateClock(CAN_500KBPS, MCP_8MHZ);
  if (err == ERROR_OK) err = MCP_setNormalMode();

  // TIM9 input capture and the shared ultrasonic trigger output.
  HC_SR04_Init();

  last_heartbeat = HAL_GetTick();
  last_pid_time = HAL_GetTick();

  /* USER CODE END 2 */

  /* Infinite loop */
  /* USER CODE BEGIN WHILE */
  while (1)
  {
    /* USER CODE BEGIN WHILE */

    // ── Poll CAN messages ──
    can_frame rx_frame;
    if (MCP_readMessage(&rx_frame) == ERROR_OK) {

      // Velocity command (0x100): 4× int16 target RPM, order = MOTOR_FL/FR/RL/RR
      if (rx_frame.can_id == CAN_ID_VEL_CMD && rx_frame.can_dlc == 8) {
        int16_t rpm[4];
        memcpy(rpm, rx_frame.data, 8);
        for (int i = 0; i < NUM_MOTORS; i++) {
          motors[i].target_rpm = rpm[i];  // i indexes MotorPosition directly
        }
      }

      // Heartbeat (0x300)
      if (rx_frame.can_id == CAN_ID_HEARTBEAT) {
        last_heartbeat = HAL_GetTick();
      }
    }

    // ── Heartbeat alive? ──
    // If not, we must skip the control update entirely (below), otherwise the
    // control block would immediately re-drive the PWM that motors_stop() just
    // cleared, defeating the emergency stop.
    uint8_t hb_ok = (HAL_GetTick() - last_heartbeat <= HEARTBEAT_TIMEOUT_MS);
    if (!hb_ok) {
      motors_stop();
    }

    // ── Motor control + encoder send @ 20ms ──
    uint32_t now = HAL_GetTick();
    if (now - last_pid_time >= PID_INTERVAL_MS) {
#if USE_PID
      float dt = (now - last_pid_time) / 1000.0f;
      static int32_t prev_ticks[NUM_MOTORS] = {0};
#endif
      last_pid_time = now;

      for (int i = 0; i < NUM_MOTORS; i++) {
        // Always update the encoder (needed for cumulative ticks + CAN, and
        // so 16-bit timers don't silently wrap between reads), even when the
        // heartbeat is dead and motors are stopped.
        encoder_update(&motors[i]);

#if USE_PID
        // Closed-loop speed control with encoder-direction correction.
        int32_t delta = motors[i].cum_ticks - prev_ticks[i];
        prev_ticks[i] = motors[i].cum_ticks;
        float actual_rpm = (ENC_SIGN[i] * delta * 60.0f) / (dt * ENCODER_CPR);

        if (hb_ok) {
          float target = (float)motors[i].target_rpm;
          float output = pid_compute(&motors[i].pid, target, actual_rpm, dt);
          int32_t duty = (int32_t)(output * PWM_PERIOD / MAX_RPM);
          motor_set_pwm(&motors[i], duty);
        } else {
          // Emergency stop: keep motors off and reset PID state so the
          // integrator can't wind up while stopped (no bump on restart).
          motors[i].pid.integral = 0.0f;
          motors[i].pid.prev_error = 0.0f;
          motor_set_pwm(&motors[i], 0);
        }
#else
        // Open-loop: joystick target RPM maps straight to PWM duty. No
        // encoder feedback in the control path, so the reversed-encoder
        // polarity cannot cause runaway. motor_set_pwm() handles direction
        // sign and clamps magnitude to PWM_PERIOD.
        if (hb_ok) {
          int32_t duty = (int32_t)((float)motors[i].target_rpm * PWM_PERIOD / MAX_RPM);
          motor_set_pwm(&motors[i], duty);
        } else {
          motor_set_pwm(&motors[i], 0);
        }
#endif
      }

      // ── Send encoder data ──
      // Frame 0x200: MOTOR_FL + MOTOR_FR
      can_frame tx0;
      tx0.can_id = CAN_ID_ENCODER_0;
      tx0.can_dlc = 8;
      memcpy(&tx0.data[0], &motors[MOTOR_FL].cum_ticks, 4);
      memcpy(&tx0.data[4], &motors[MOTOR_FR].cum_ticks, 4);
      MCP_sendMessage(&tx0);

      // Frame 0x201: MOTOR_RL + MOTOR_RR
      can_frame tx1;
      tx1.can_id = CAN_ID_ENCODER_1;
      tx1.can_dlc = 8;
      memcpy(&tx1.data[0], &motors[MOTOR_RL].cum_ticks, 4);
      memcpy(&tx1.data[4], &motors[MOTOR_RR].cum_ticks, 4);
      MCP_sendMessage(&tx1);

      // Service one sequential right/back ultrasonic cycle. StartMeasurement
      // is a no-op while a cycle is active, so this remains non-blocking apart
      // from the 12 us trigger pulse.
      if (HC_SR04_IsComplete()) {
        HC_SR04_Result ultrasonic = HC_SR04_GetResult();
        can_frame tx_ultrasonic;
        tx_ultrasonic.can_id = CAN_ID_ULTRASONIC;
        tx_ultrasonic.can_dlc = 5;
        tx_ultrasonic.data[0] = (uint8_t)(ultrasonic.right_mm & 0xFFU);
        tx_ultrasonic.data[1] = (uint8_t)(ultrasonic.right_mm >> 8);
        tx_ultrasonic.data[2] = (uint8_t)(ultrasonic.back_mm & 0xFFU);
        tx_ultrasonic.data[3] = (uint8_t)(ultrasonic.back_mm >> 8);
        tx_ultrasonic.data[4] = ultrasonic.status;
        MCP_sendMessage(&tx_ultrasonic);
      }
      HC_SR04_StartMeasurement();
    }

    HAL_Delay(1);
    /* USER CODE END WHILE */

    /* USER CODE BEGIN 3 */
  }
  /* USER CODE END 3 */
}

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


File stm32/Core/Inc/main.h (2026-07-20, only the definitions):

#define TRIG_Pin GPIO_PIN_4
#define TRIG_GPIO_Port GPIOA
#define Motor1_1_Pin GPIO_PIN_0
#define Motor1_1_GPIO_Port GPIOB
#define Motor1_2_Pin GPIO_PIN_1
#define Motor1_2_GPIO_Port GPIOB
#define Motor2_1_Pin GPIO_PIN_2
#define Motor2_1_GPIO_Port GPIOB
#define Motor2_2_Pin GPIO_PIN_10
#define Motor2_2_GPIO_Port GPIOB
#define Motor3_1_Pin GPIO_PIN_12
#define Motor3_1_GPIO_Port GPIOB
#define Motor3_2_Pin GPIO_PIN_13
#define Motor3_2_GPIO_Port GPIOB
#define Motor4_1_Pin GPIO_PIN_14
#define Motor4_1_GPIO_Port GPIOB
#define Motor4_2_Pin GPIO_PIN_15
#define Motor4_2_GPIO_Port GPIOB
#define INT_Pin GPIO_PIN_8
#define INT_GPIO_Port GPIOB
#define INT_EXTI_IRQn EXTI9_5_IRQn
#define CS_Pin GPIO_PIN_9
#define CS_GPIO_Port GPIOB

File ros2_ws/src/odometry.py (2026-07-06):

"""
odometry.py
X-drive forward kinematics + midpoint pose integration.

Consumes cumulative encoder tick counts (already 32-bit extended on the
STM32 side, overflow-safe) for the four wheels and produces:
  - body-frame velocities (vx, vy, omega)
  - accumulated world-frame pose (x, y, theta)

Design notes (see PROJECT_STATE.md decision log, 2026-07-03):
  - dt is computed from actual CAN frame arrival timestamps, not assumed
    fixed at 20ms, to avoid absorbing bus/scheduling jitter as bias.
  - Pose integration uses the midpoint method (heading evaluated at
    t + dt/2) rather than plain Euler, since heading error dominates
    translational error in accumulated odometry drift.
  - MOTOR_MAP / ENCODER_SIGN are pulled out as explicit config so wiring
    changes don't require touching the math.
  - ENCODER_CPR below was empirically calibrated 2026-07-04 (rotate each
    output shaft 10 turns by hand, average the raw CNT delta across all
    four wheels): measured 2779 vs theoretical 2800. ENCODER_SIGN was
    calibrated the same day (all four wheels count down on forward drive
    -> all -1).
"""

import math

# ---- Physical / calibration constants ----
WHEEL_RADIUS_M = 0.025       # 50mm diameter / 2
CENTER_TO_WHEEL_M = 0.115    # R: center to wheel contact point

# X-drive wheels sit at 45deg, so a wheel driving pure +vx contributes only
# cos(45)=1/sqrt(2) of its surface speed to vx. The drive-side inverse
# kinematics (PS2_Drive_Test.py) -- which the forward kinematics below inverts
# -- uses the un-normalized form (coefficient 1, not 1/sqrt2), so the
# translation terms come out low by 1/sqrt(2). CALIBRATED 2026-07-06 (foam
# ground truth, data/Week4 Trials.xlsx): forward AND strafe read ~0.74x the
# tape-measured distance while in-place rotation read ~1.0 -- exactly the
# missing cos45 factor (rotation uses R and is unaffected). Multiply the
# translation output by sqrt(2) to correct; omega is left untouched.
TRANSLATION_SCALE = math.sqrt(2)
ENCODER_CPR = 2779           # CALIBRATED 2026-07-04: 4-wheel avg of 10-rev hand turns
                             # (FL 2779.5, FR 2778.3, RL 2778.7, RR 2777.6 -> 2778.5).
                             # Theoretical was 2800 (7 PPR * 4x quad * 100 gear); measured
                             # ~0.8% lower, spread across wheels only ~0.07%.

# Encoder index -> physical wheel position.
#
# This map reflects the ENCODER wiring harness, which is INDEPENDENT of the
# motor/drive wiring. On the drive side (main.c MotorPosition enum,
# ps2_drive_test.py inverse kinematics) index 0/1/2/3 = fl/fr/rl/rr:
#   fl = vx + vy + omega*R
#   fr = vx - vy - omega*R
#   rl = vx - vy + omega*R
#   rr = vx + vy - omega*R
# but CALIBRATED 2026-07-06 (hand-spin each wheel, watch encoder_monitor):
# the REAR encoders are physically swapped -- encoder index 2 sits on the
# RR wheel and index 3 on the RL wheel. Symptom before the fix was vy and
# omega swapped (spin-in-place read as y, strafe read as omega) while vx
# was fine. So indices 2/3 below are DELIBERATELY the opposite of the drive
# order; do NOT "align" them back to the enum without re-checking the
# encoder harness.
MOTOR_MAP = {
    0: "fl",
    1: "fr",
    2: "rr",   # index 2 encoder is physically on the RR wheel
    3: "rl",   # index 3 encoder is physically on the RL wheel
}

# Per-motor encoder count sign correction. Flip an entry to -1 if that
# wheel's raw tick count increases when the wheel is actually spinning
# "backward" relative to the inverse-kinematics convention above (e.g.
# mirrored mounting).
#
# CALIBRATED 2026-07-04: driving straight forward (pure +vx, all four
# wheels command +) made ALL FOUR raw tick counts DECREASE, so all four
# are flipped to -1. NOTE: the pure-vx test fully determines these signs
# (each wheel must read + on forward) -- there is no remaining freedom to
# fix strafe/rotation via ENCODER_SIGN. vy (strafe) and omega (spin)
# direction correctness must still be confirmed by the ground-truth test
# (square path + 360 spin, Task 4). If those come out mirrored it's a
# geometry/wiring issue, NOT re-tunable here.
ENCODER_SIGN = {
    0: -1,
    1: -1,
    2: -1,
    3: -1,
}


def ticks_to_wheel_velocity(delta_ticks: int, dt: float) -> float:
    """Convert a tick delta over dt seconds into linear wheel velocity (m/s)."""
    if dt <= 0:
        return 0.0
    rev_per_sec = (delta_ticks / dt) / ENCODER_CPR
    return rev_per_sec * 2.0 * math.pi * WHEEL_RADIUS_M


class OdometryEstimator:
    """Stateful x-drive odometry: raw encoder ticks -> world-frame pose.

    Call update() once per received encoder CAN frame pair (all 4 motors'
    cumulative tick counts, plus the timestamp they were read at). This
    class knows nothing about CAN/ROS -- feed it plain ticks + timestamp,
    it hands back plain numbers. Wire it up inside can_bridge_node.py.
    """

    def __init__(self, x: float = 0.0, y: float = 0.0, theta: float = 0.0):
        self.x = x
        self.y = y
        self.theta = theta
        self._last_ticks = None       # dict[int, int], None until first sample
        self._last_timestamp = None   # float seconds, None until first sample

    def update(self, motor_ticks: dict, timestamp: float):
        """
        motor_ticks: {0: int, 1: int, 2: int, 3: int} cumulative ticks
        timestamp:   seconds (e.g. time.monotonic() at CAN frame arrival)

        Returns (x, y, theta, vx, vy, omega) after this update, or None on
        the very first call (nothing to differentiate against yet).
        """
        if self._last_ticks is None:
            self._last_ticks = dict(motor_ticks)
            self._last_timestamp = timestamp
            return None

        dt = timestamp - self._last_timestamp
        if dt <= 0:
            # Out-of-order or duplicate frame; skip rather than divide by
            # zero or integrate backward in time.
            return None

        wheel_vel = {}
        for motor_idx, position in MOTOR_MAP.items():
            delta = motor_ticks[motor_idx] - self._last_ticks[motor_idx]
            delta *= ENCODER_SIGN[motor_idx]
            wheel_vel[position] = ticks_to_wheel_velocity(delta, dt)

        fl, fr = wheel_vel["fl"], wheel_vel["fr"]
        rl, rr = wheel_vel["rl"], wheel_vel["rr"]
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

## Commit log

2026-06-26 Initial commit: XDrive SLAM base framework
    [Bottom V2.SLDPRT, Bottom V2.STL, Bottom V3.STL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]
2026-07-04 Week 3: heartbeat fix, encoder monitor script, main.c sync
    - PS2_Drive_Test.py: add heartbeat thread (0x300 @ 100ms) to prevent
    STM32's 200ms timeout from shutting down motors during PS2 driving
    - encoder_monitor.py: new standalone CAN listener for real-time encoder
    tick calibration (Task 2); prints delta from baseline for 4 wheels
    - main.c: full 4-motor PID + encoder + heartbeat + MotorPosition enum
    - PROJECT_STATE.md: update status, log can_bridge_node.py import bug
    [PS2_Drive_Test.py, encoder_monitor.py, main.c]
2026-07-05 add some other files
    [schematic.fzz]
2026-07-05 Week 3: apply encoder calibration (SIGN all -1, CPR 2779)
    Real-hardware calibration on RPi 2026-07-04:
    - ENCODER_SIGN: forward drive made all four encoders count down, so
    all four flipped to -1. Pure-vx test fully constrains these; vy/omega
    direction still pending ground-truth verification (Task 4).
    - ENCODER_CPR: 2800 -> 2779, from 4-wheel avg of 10-rev hand turns
    (FL 2779.5 / FR 2778.3 / RL 2778.7 / RR 2777.6). main.c CPR left at
    2800 intentionally (PID feedback only, ~0.8% off, not worth a reflash).
    - Smoke test inputs negated to match reversed encoders; still passes
    (pure +vy -> vx=0, omega=0, vy>0).
    [odometry.py]
2026-07-05 Week 3: integrate OdometryEstimator into can_bridge_node, fix imports
    - can_bridge_node.py: assemble 4-motor ticks from 0x200+0x201, call
    OdometryEstimator.update() using the CAN frame timestamp for dt,
    publish nav_msgs/Odometry on 'odom' + odom->base_link TF. Added a
    throttled ~2Hz pose log for the ground-truth sanity check.
    - Fixed broken imports: can_bridge.protocol/can_interface -> flat
    protocol/can_interface/odometry, matching every other script here
    (there is no can_bridge/ colcon package on disk).
    - PROJECT_STATE.md: Task 5 done, import-bug pitfall resolved, decision
    log for odom trigger timing + flat-import choice.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
    [can_bridge_node.py]
2026-07-05 STM32: switch to open-loop control, fix heartbeat e-stop
    Motors ran away to full speed on power-up with the joystick unresponsive.
    Root cause: all four encoders count backwards vs motor drive (calibrated
    2026-07-04), so the PID speed loop used reversed feedback = positive
    feedback = runaway. Gains were never the issue.
    - Add #define USE_PID (default 0). Open-loop maps joystick target RPM
    straight to PWM duty, with no encoder feedback in the control path, so
    the reversed encoders cannot cause runaway. PID + ENC_SIGN correction
    are retained behind #if USE_PID for the future cmd_vel phase.
    Open-loop is also better for Week 4: closed loop would mask the motion
    uncertainty we want to m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
    [main.c]
2026-07-06 can_bridge_node: ignore looped-back RPi->STM32 frames
    SocketCAN echoes frames sent by other local sockets (e.g. PS2_Drive_Test
    transmitting 0x100/0x300) onto the node's socket. decode() only handles
    STM32->RPi telemetry, so those command IDs fell through to the 'unknown
    ID' warning and flooded the log. Skip the known outgoing IDs (0x100,
    0x300, 0x400-0x402) quietly before decoding.
    [can_bridge_node.py]
2026-07-06 odometry: fix swapped RL/RR encoders in MOTOR_MAP
    Ground-truth direction check showed vy and omega swapped (spin-in-place
    read as y, strafe read as omega) while vx was fine. Hand-spinning each
    wheel with encoder_monitor confirmed the rear encoders are physically
    swapped: encoder index 2 is on the RR wheel, index 3 on the RL wheel.
    - MOTOR_MAP: index 2/3 -> rr/rl (was rl/rr). This reflects the ENCODER
    harness, which is independent of the motor wiring, so it deliberately
    differs from main.c's MotorPosition enum on the rear two. Odometry-only
    change, no reflash. ENCODER_SIGN (all -1) and ENCODER_CPR (2779) unchanged.
    - Rewrote the smoke test to construct its raw-tick input by inverting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
    [odometry.py]
2026-07-06 odometry: flip vy/omega sign to REP-103 (left=+y, CCW=+omega)
    Ground-truth direction check after the RL/RR encoder-map fix: left strafe
    read as -vy and CCW spin as -omega while vx (forward) was correct. That
    "vx right, vy+omega both mirrored" pattern is a left-right frame mirror --
    the drive inverse-kinematics convention has +vy=right, +omega=CW. Since
    ENCODER_SIGN is pinned by the forward test and MOTOR_MAP by the physical
    encoder harness, the flip can only live in the forward kinematics output.
    Negate vy/omega; leave vx untouched. Smoke test + PROJECT_STATE updated.
    [odometry.py]
2026-07-06 odometry: bake in sqrt2 translation scale; PS2: add D-pad fine-adjust
    - odometry.py: add TRANSLATION_SCALE=sqrt(2) on vx/vy for the missing
    cos(45deg) factor (X-drive wheels at 45deg; un-normalized inverse
    kinematics dropped it). Foam ground truth read translation ~0.74x actual
    while rotation read ~1.0 -- the classic missing-cos45 signature. omega
    untouched. Drive-side inverse kinematics deliberately left as-is.
    - PS2_Drive_Test.py: map D-pad to a fixed low-RPM (MICRO_RPM=50) crawl
    (up/down=fwd/back, left/right=strafe) so the robot can be nudged onto
    floor marks during ground-truth tests; sticks are too coarse.
    - PROJECT_STATE.md: decision-log entries for both.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
    [PS2_Drive_Test.py, odometry.py]
2026-07-07 Modified PS2 controller
    [Week4 Trials.xlsx]
2026-07-20 week5: HC-SR04 ultrasonic pipeline + calibrated beam model
    STM32: TIM9 input-capture driver for two HC-SR04 sensors (right/back),
    sequential measurement with shared trigger (PA4), echo on PA2/PA3.
    Integrated into 20ms control loop, sends CAN 0x202.
    RPi: protocol.py decode for 0x202, can_bridge_node publishes
    sensor_msgs/Range on /ultrasonic/right and /ultrasonic/back.
    ultrasonic_collect.py for systematic data collection,
    ultrasonic_analyze.py for noise model fitting.
    Perception: BeamModel (Prob Robotics Ch.6 four-component beam model)
    and GaussianModel with distance-dependent sigma support. RectMap
    with 2D ray casting. Parameters calibrated from HC-SR04 bench data
    (100/300/600/1000mm, 100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
    [SummerSLAM.ioc, can_bridge_node.py, hc_sr04.c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]
2026-07-20 week5: archive calibration data + update PROJECT_STATE.md
    Add bench calibration (2 sensors × 4 distances × 100 samples) and
    map validation (4 positions × 100 samples) CSVs to data/ultrasonic/.
    Update PROJECT_STATE.md: add Week 5 completion checklist, ultrasonic
    pin assignments, noise model parameters, decision log entries, and
    advance next-steps to Week 6 MCL.
    [bench_calibration.csv, bench_summary.csv, map_validation.csv]
2026-07-22 week6: MCL particle filter design spec
    Design for Monte Carlo Localization (Prob Robotics Ch.8): mcl.py core
    algorithm, mcl_offline.py replay + GIF animation, mcl_node.py online
    (phase 2). Standard MCL with low-variance resampling, odometry-based
    motion noise, and the Week 5 calibrated BeamModel for measurement update.
2026-07-26 docs: revise week 3 odometry guide
2026-08-04 docs: STE pass and remove redundant negation tails across weeks 1-6
    Apply ASD-STE100 pragmatic rules: replace banned modals (could→can,
    would→restructure, should→must, may→can), unify vocabulary to "verify"
    and "configuration", remove semicolons, fix passive voice. Delete all
    ", not Y" redundant tail patterns.
2026-08-04 docs: write week 6 MCL chapter from branch code and design spec
    Covers particle state, holonomic body-frame motion model, measurement
    update in log space, low-variance resampling, noise floor calibration,
    CSV replay pipeline, convergence test results (2.3cm MCL vs 6.2cm dead
    reckoning), and heading observability limits.
2026-08-09 add camera calibration scripts and checkerboard pattern
    camera_utils.py: shared module with 180-degree flip for upside-down webcam
    calibration_capture.py: interactive checkerboard image capture with live preview
    calibrate_camera.py: runs cv2.calibrateCamera, outputs YAML with intrinsics
    checkerboard_9x6_30mm.png: 9x6 inner corners, 30mm squares, 300 DPI for A4
    [calibrate_camera.py, calibration_capture.py]
2026-08-09 fix: update camera device to /dev/video0
2026-08-09 add camera calibration results (C270, RMS 0.377)
    [calibration.yaml]
2026-08-09 add monocular visual odometry (ORB + epipolar geometry)
2026-08-09 add VO vs encoder trajectory comparison tools
2026-08-09 add motor channel diagnostic script for RR issue
    [motor_diag.py]
2026-08-09 fix motor_diag: test M1 (FR) instead of M3
    [motor_diag.py]
2026-08-09 add merged VO+encoder capture script, fix VO pipeline
    - vo_encoder_capture.py: single-process simultaneous capture with shared
    clock, --headless mode for SSH
    - VO fixes: Lowe's ratio test, R_w.T@t world-frame accumulation,
    jump filter, 1500 ORB features
    - plot_vo_vs_encoder.py: reads merged CSV, temporal alignment, x/y vs time
    [plot_vo_vs_encoder.py, vo_encoder_capture.py]
2026-08-09 Rpi data seg2
    [vo_encoder_data.csv]
2026-08-09 fix VO: remove broken jump filter (t is always unit vector)
    recoverPose returns unit-length t, so norm(t_world) ≈ 1.0 always.
    MAX_T_JUMP=0.8 rejected every single frame. Replace with inlier
    ratio filter (MIN_INLIER_RATIO=0.3) which actually measures
    estimation quality.
    [vo_encoder_capture.py]
2026-08-09 visual test 3
    [vo_encoder_data.csv]
2026-08-09 visual test 4
    [vo_encoder_data.csv]

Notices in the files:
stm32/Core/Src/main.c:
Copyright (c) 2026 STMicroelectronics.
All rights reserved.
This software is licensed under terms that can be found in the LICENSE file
